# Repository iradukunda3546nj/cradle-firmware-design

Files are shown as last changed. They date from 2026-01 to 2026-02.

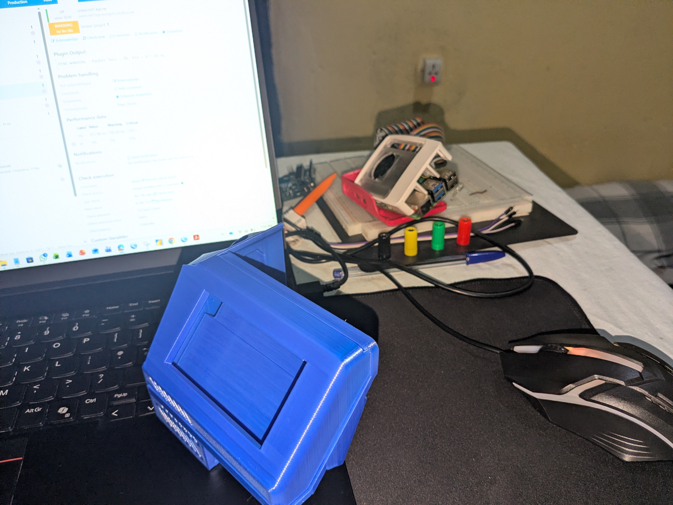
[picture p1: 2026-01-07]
Design Files/des8.jpg

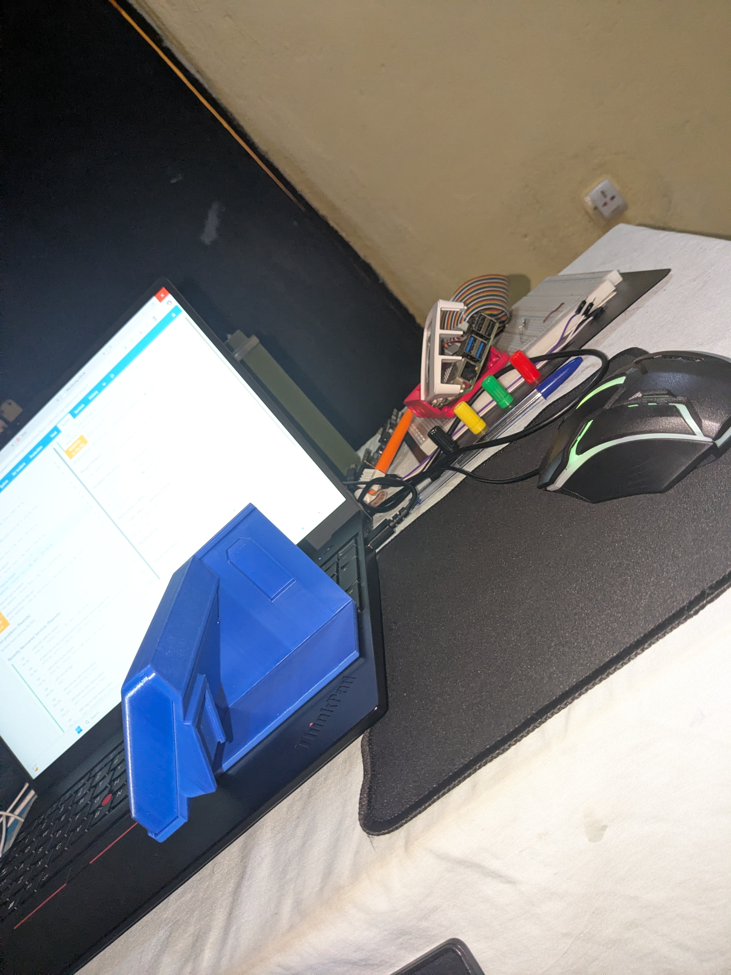
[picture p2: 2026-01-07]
Design Files/des6.jpg

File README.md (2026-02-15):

<<<<<<< HEAD
Git clone

=================

> git clone https://github.com/the-raspberry-pi-guy/lcd

>ls

>cd lcd

>sudo sh install.sh

>Reboot

>Run the demo file as follows:

>python demo_lcd.py  (when you get a Remote I/O error : the problem is on the wrong I2C address of your peripheral connected to the I2C of Raspebrry pi.  

>open lcddriver.py

> nano demo_lcd.py   (check if the I2C address of your lcd matches with the one in the code  : 

 (Here is how to detect the I2C address of your I2C device  : first run

> sudo apt update

> sudo apt install i2c-tools

> Then run : > sudo i2cdetect -y 1    (Note: Please ensure that the I2C is enabled in raspberry pi configurations > raspi-config

If you found that the address of your lcd do not match with the one in the code edit it right and save and exit using the following command

>Ctrl + O → Enter → Ctrl + X

;After running all above I get the realization of this :

Creating VEnv so that you're able to install the libraries using pip:

# Create virtual environment

> python3 -m venv cradlex_env

# Activate the virtual environment

> source cradlex_env/bin/activate

Using Secure copy command

========================================

>scp "D:/cradle-firmware-design/lcdTemp.py" cradle@192.168.1.81:~/       

From Pi to local PC
use e.g > scp cradle@192.168.1.81:~/test.wav "D:/cradle-firmware-design/"                    

                  Re-working on The project

==========================================================================

Recall: to test LCD (we need to go to the lcd folder and run demo_lcd.py)  using the following commands

>cd lcd

>python3 demo_lcd.py

                             Looking for connecting DHT temperature sensor to Rpi

============================================================================================

I have found many works done on connecting DHT sensor to the raspberrypi.However, many of them do not work, when you try to run them you face a runtime error, and this issue might be arising from the lgpio missing library, the one which allows you to interact with the hardware GPIO pins.

Hopefully, Here's a detailed guide to help you connect the digital temperature sensor to the raspberryPi (Go step by step throughout this entire guide).

> https://pimylifeup.com/raspberry-pi-humidity-sensor-dht22/

Now, Let's proceed with installing and connecting RaspberryPi to the edge impulse platform for sending data for model training

===============================================================================

Meanwhile, you can connect the MIC (for me ,I used USB microphone) , CSI camera. (for other sensors you can refer to the way I connected MPU6050 to edge impulse using raspberrypi i.e the way I wrote Python SDK containing API keys of the project).

In fact, connecting raspberrypi to the edge impulse platform requires installing dependencies and the there is an official edge impulse link which streamline process of connecting raspberrypi to the edge impulse 

Follow this:
          >https://docs.edgeimpulse.com/hardware/boards/raspberry-pi-5 

>Then, after you install all dependencies step by step you will run edge_impulse-linux and you will be connected to edge immediately asking you to put the edge impulse account credentials and once you enter them correctly your pi will be connected to edge ,head to that project and then go to devices, then you can start acquiring data from Pi.

                                   Integration of Sensor's data with I2C Lcd Display
===========================================================================================================
The goal was to run all components inside a virtual environment and display real‑time sensor data on the LCD.

During integration, several errors occurred due to legacy libraries, Pi 5 hardware changes, and virtual environment isolation.

This document records each error, its cause, and the exact fix.

Error 1: ModuleNotFoundError: No module named 'smbus'
Error Message

ModuleNotFoundError: No module named 'smbus'

Where it occurred

from smbus import SMBus

Inside:

drivers/i2c_dev.py
Root Cause

The LCD driver uses I2C communication

I2C requires SMBus bindings

smbus is not available inside Python virtual environments by default

Raspberry Pi OS installs smbus at system level, not venv level

Fix Applied (Step‑by‑Step)

Installed system I2C support:

sudo apt update
sudo apt install -y python3-smbus i2c-tools

Installed venv‑compatible SMBus library:

source cradlex_env/bin/activate
pip install smbus2

Updated LCD driver import:

❌ Old:

from smbus import SMBus

✅ New:

from smbus2 import SMBus
Result

✔ SMBus error resolved ✔ I2C communication functional inside virtual environment

Error 2: ModuleNotFoundError: No module named 'RPi'
Error Message
ModuleNotFoundError: No module named 'RPi'
Where it occurred
from RPi.GPIO import RPI_REVISION

Inside:

drivers/i2c_dev.py
Root Cause

Raspberry Pi 5 does not support RPi.GPIO properly

RPi.GPIO is deprecated on Pi 5

Pi 5 officially uses lgpio / libgpiod

The LCD driver was written for older Pi models (3/4)

Virtual environments do not inherit system GPIO libraries

Important Insight

The LCD driver does not actually need GPIO — it only checks RPI_REVISION to guess the I2C bus.

On modern Raspberry Pi models:

I2C bus is always bus 1

Fix Applied (Safe & Engineered)

Modified the driver to gracefully bypass RPi.GPIO:

❌ Old code:

from RPi.GPIO import RPI_REVISION

✅ New code:

try:
    from RPi.GPIO import RPI_REVISION
except ImportError:
    RPI_REVISION = 3  # Safe default for modern Raspberry Pi
Why this works

Avoids installing deprecated RPi.GPIO

Fully compatible with Raspberry Pi 5

Keeps driver future‑proof

Does not interfere with lgpio

Result

✔ GPIO error resolved ✔ LCD driver loads correctly ✔ No conflicts with lgpio

Error 3: Degree Symbol Displaying Incorrectly (-C instead of °C)
Symptom

LCD showed:

25.3-C

Instead of:

25.3°C
Root Cause

HD44780 LCDs do not support Unicode

Unicode degree symbol ° is not part of LCD character ROM

Fix Applied

Used the HD44780‑native degree symbol code:

DEGREE = chr(223)

And updated formatting:

f"{temperature:.1f}{DEGREE}C"
Result

✔ Correct °C symbol displayed

                                         📦 Weighing System Module (Raspberry Pi 5 + HX711 + I2C LCD)
==================================================================================================================================================

1️⃣ Objective

This module adds a reliable digital weighing function to the Raspberry Pi 5 using:

20kg Load Cell

HX711 24-bit ADC amplifier

I2C LCD display

Kalman filtering for stable readings

The goal is to:

Accurately measure weight in kilograms

Provide stable filtered readings

Support calibration using a known weight

Run fully inside a Python virtual environment (cradlex_env)

Be compatible with Raspberry Pi 5 (using lgpio, not RPi.GPIO)

The system is designed for workshop/small-business grade reliability, not hobby-level testing.

2️⃣ Hardware Wiring
HX711 → Raspberry Pi 5 (BCM Numbering)
HX711 Pin	Raspberry Pi 5
DT (DOUT)	GPIO 5
SCK	GPIO 6
VCC	5V
GND	GND

Important Notes:

BCM numbering is used.

Ensure common ground.

Load cell must be mechanically fixed.

Allow 5–10 minutes warm-up before calibration.

3️⃣ Virtual Environment Setup

Activate environment:

source cradlex_env/bin/activate

Install required libraries:

pip install lgpio numpy pyyaml smbus2 RPLCD

System-level dependency:

sudo apt install python3-smbus i2c-tools

4️⃣ Calibration Procedure (calibrate.py)
Purpose

Calibration determines:

zero_offset

calibration_factor

These values convert raw HX711 counts into kilograms.

How It Works

User removes all weight → system measures raw zero value.

User places a known weight → system measures span.

Calibration factor is computed:

calibration_factor = (span_raw - zero_raw) / known_weight

Values are saved into:

config.yaml

How To Run
python3 calibrate.py

Steps:

Remove all weight → press Enter

Enter known weight in kg (e.g., 5)

Place weight → wait stable → press Enter

After completion:

config.yaml

will contain:

zero_offset: XXXXX
calibration_factor: XXXXX

Verification After Calibration

Run:

python3 weighing_system.py

Check:

No load → ~0.000 kg

Known weight → correct value

Remove weight → returns to zero

If slight error exists, fine-tune:

new_factor = old_factor × (measured / real_weight)

5️⃣ Main Weighing Program (weighing_system.py)
Objective

This program:

Reads raw HX711 data

Converts to kg using stored calibration

Applies Kalman filtering

Displays weight on I2C LCD

Runs continuously

Weight Calculation
weight = (raw - zero_offset) / calibration_factor

Filtering

A Kalman filter is applied to:

Reduce noise

Improve stability

Provide smooth readings

Maintain responsiveness

Display

The system shows:

X.XXX kg

Updated continuously.

6️⃣ Important Issue Encountered (SMBus Error)
Problem

While running weighing_system.py, the following error occurred:

NameError: name 'SMBus' is not defined

Root Cause

Inside:

cradlex_env/lib/python3.13/site-packages/RPLCD/i2c.py

The library internally attempted:

self.bus = SMBus(self._port)

However, the module was imported as:

import smbus2 as smbus

This means:

SMBus was not directly defined

Only smbus.SMBus existed

Hence → NameError.

Solution Applied

Opened the file:

nano cradlex_env/lib/python3.13/site-packages/RPLCD/i2c.py

Searched for:

SMBus(

Replaced:

self.bus = SMBus(self._port)

With:

self.bus = smbus.SMBus(self._port)

Saved file.

Result

✔ SMBus error resolved
✔ I2C LCD working inside virtual environment
✔ No need for RPi.GPIO
✔ Compatible with Raspberry Pi 5

7️⃣ Raspberry Pi 5 Compatibility Notes

RPi.GPIO was avoided due to compatibility issues.

lgpio is used instead.

I2C bus on Raspberry Pi 5 is always bus 1.

Virtual environments require smbus2.

8️⃣ Final System Overview

The weighing module now provides:

✔ Pi 5 compatible GPIO control (lgpio)
✔ HX711 24-bit ADC reading
✔ Proper calibration storage
✔ Kalman-filtered stable readings
✔ I2C LCD output
✔ Fully virtual-environment compatible

9️⃣ Future Improvements (Optional)

Add tare button

Add multi-point calibration

Add temperature compensation

Add data logging

Add automatic startup (systemd service)

🔚 Conclusion

The weighing function is now:

Stable

Accurate

Pi 5 compatible

Professionally structured

Fully reproducible from documentation

This documentation ensures future maintenance and upgrades can be performed confidently.

               real embedded-to-server integration || integrating/ sending sensor's data to the cloud platform for Data collection purposes
=================================================================================================================================

=======
>>>>>>> 16ca65192366029ca63078be4c56230614e71125

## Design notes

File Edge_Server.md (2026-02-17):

🌐 Smart Cradle IoT Backend Architecture
📌 System Overview

The Smart Cradle system follows a structured IoT architecture:

Raspberry Pi (Edge Device)
        ↓
HTTP POST Requests (REST API)
        ↓
Server-Side PHP API
        ↓
MySQL Database
        ↓
Dashboard (HTML + CSS + JS)

The project is hosted under:

https://www.zolilabs.com/smart_cradle/

📂 Server Directory Structure

The deployed server folder:

smart_cradle/
│
├── api/
├── audio/
├── dashboard/
├── db/

Each folder has a specific engineering role.

🔹 1️⃣ audio/ – Media Storage Layer
Purpose:

Stores uploaded baby audio recordings.

Logic:

When the Raspberry Pi records audio:

WAV file recorded locally

Converted to MP3

Sent via HTTP POST to:

/smart_cradle/api/upload_audio.php

upload_audio.php saves file to:

smart_cradle/audio/

File is stored with timestamp-based naming:

$fileName = time() . "_" . basename($_FILES["audio"]["name"]);

This prevents filename collisions.

🔹 2️⃣ api/ – REST API Layer

This folder acts as the communication interface between:

Raspberry Pi (device)

Database

Dashboard

It contains:

✅ upload_audio.php
Function:

Receives multipart/form-data POST request.

Logic:

Reads $_FILES["audio"]

Moves file into /audio/

Returns JSON response:

{
  "status": "success",
  "audio_url": "https://www.zolilabs.com/smart_cradle/audio/xxxx.mp3"
}

This URL is later stored in the database.

✅ receive_data.php
Function:

Receives JSON POST request from Raspberry Pi.

Example Payload:
{
  "temperature": 28.3,
  "humidity": 50.2,
  "weight": 5,
  "presence": true,
  "audio_url": "https://..."
}

Logic:

Reads raw JSON body

Decodes into PHP array

Inserts into database table

Returns response

This file is the main IoT ingestion endpoint.

✅ data.php
Function:

Acts as API endpoint for frontend/dashboard.

Purpose:

Provides structured JSON data to the dashboard.

Flow:
Database → data.php → JSON → dashboard JavaScript → UI

This separates:

Data storage logic

Presentation logic

Good engineering separation of concerns.

🔹 3️⃣ db/ – Database Layer

Contains:

Database connection file

Configuration credentials

Possibly schema definitions

Role:

Central persistent storage

Stores:

Temperature

Humidity

Weight

Presence

Audio URL

Timestamp

Acts as historical data source.

🔹 4️⃣ dashboard/ – Visualization Layer
Technology Stack:

HTML

CSS

JavaScript (AJAX / Fetch API)

Logic:

JavaScript periodically requests:

/smart_cradle/api/data.php

Receives JSON response

Dynamically updates:

Temperature display

Humidity display

Weight display

Audio playback

Charts (if implemented)

This creates real-time monitoring interface.

🔁 Complete IoT Data Flow
🔹 Step 1 – Sensor Acquisition (Edge)

Raspberry Pi:

Reads DHT22

Reads HX711 weight

Records audio

Compresses to MP3

🔹 Step 2 – Data Upload

Two separate HTTP requests:

A) Multipart Upload
POST → upload_audio.php
Content-Type: multipart/form-data

B) JSON Upload
POST → receive_data.php
Content-Type: application/json

🔹 Step 3 – Server Processing

PHP validates input

Stores file

Inserts row into MySQL

🔹 Step 4 – Dashboard Retrieval

Frontend makes:

GET → data.php

Receives structured JSON for display.

🧠 Engineering Concepts Applied

This system demonstrates:

RESTful API design

Separation of backend and frontend logic

Edge-to-cloud communication

Multipart/form-data handling

JSON-based IoT communication

Server-side file handling

Database persistence

Web dashboard integration

🔐 Hosting Incident (Bot Protection)

At one point:

LiteSpeed Bot Protection blocked POST requests

IoT device could not solve reCAPTCHA

Server returned HTML instead of JSON

Solution:
Hosting provider whitelisted:

/smart_cradle/api/

This restored automated device communication.

This highlights the importance of:

Understanding server infrastructure

Recognizing HTTP vs application-level failures

Debugging IoT network layers

🏗 Architecture Classification

The Smart Cradle is now a:

Full-stack IoT System

It integrates:

Embedded systems

Real-time sensor acquisition

Digital signal processing

HTTP networking

REST APIs

Database systems

Web dashboards

Hosting infrastructure

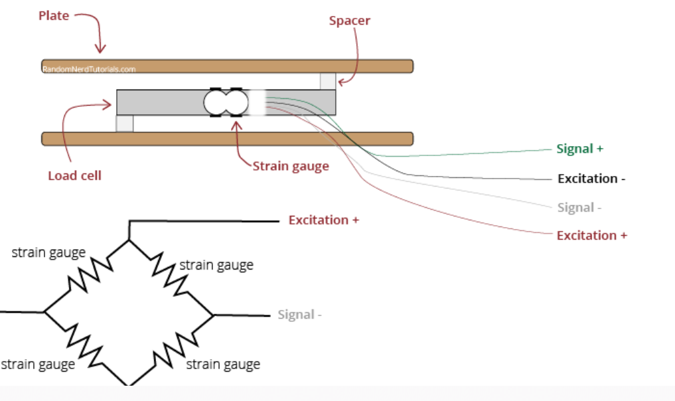
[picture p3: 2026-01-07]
LoadcellOverview.png

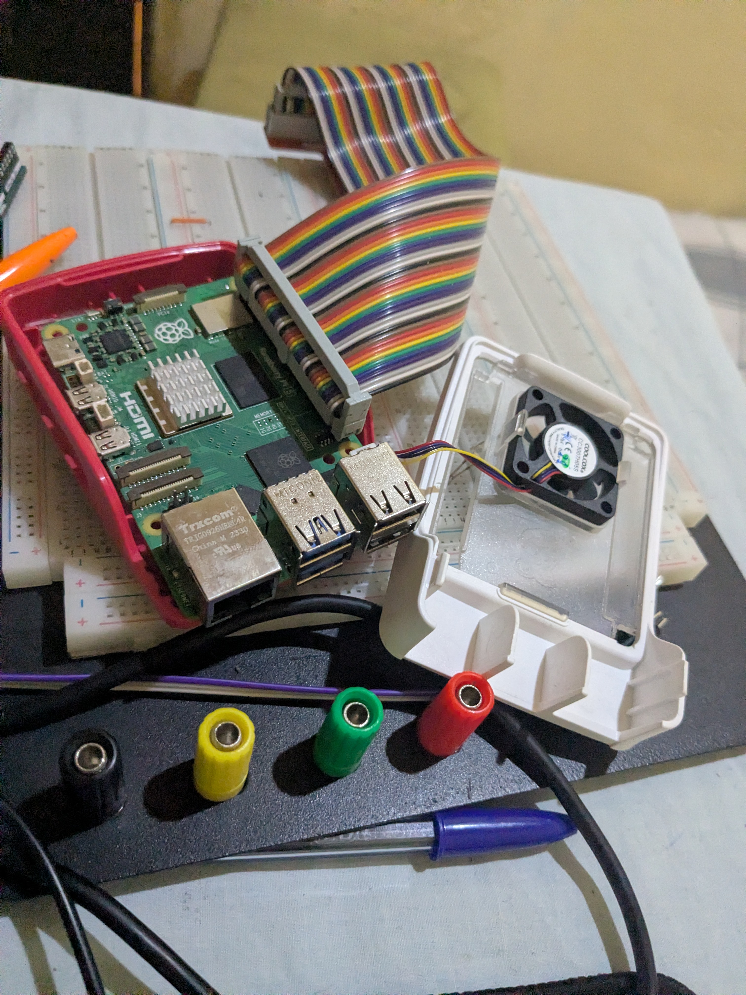
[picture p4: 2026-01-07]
Design Files/des5.jpg

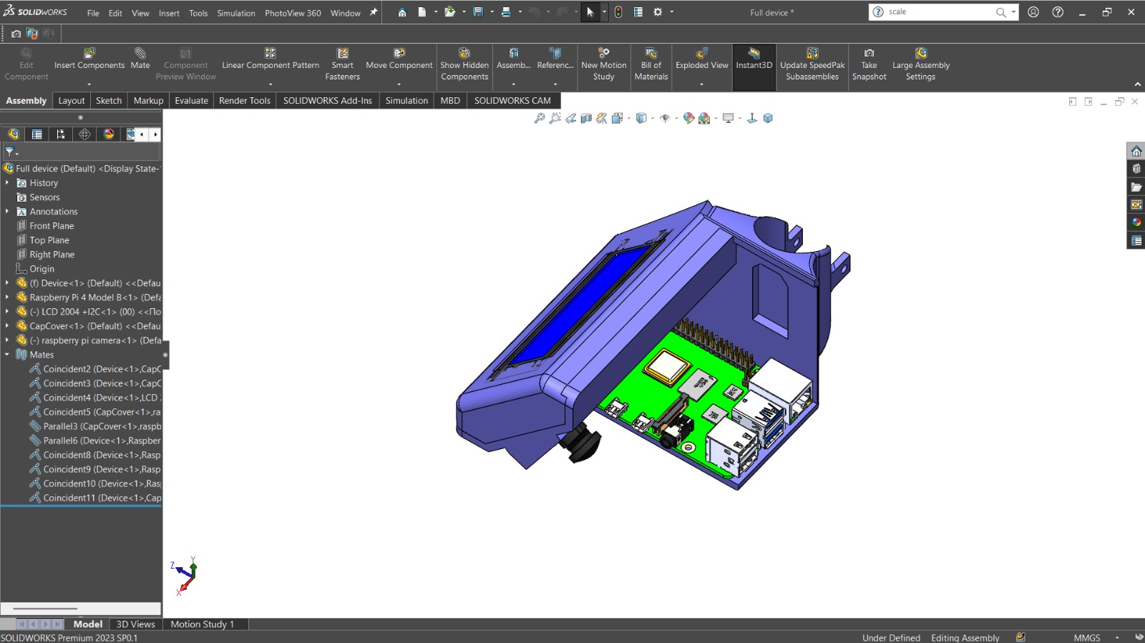
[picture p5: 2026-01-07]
Design Files/des4.jpeg

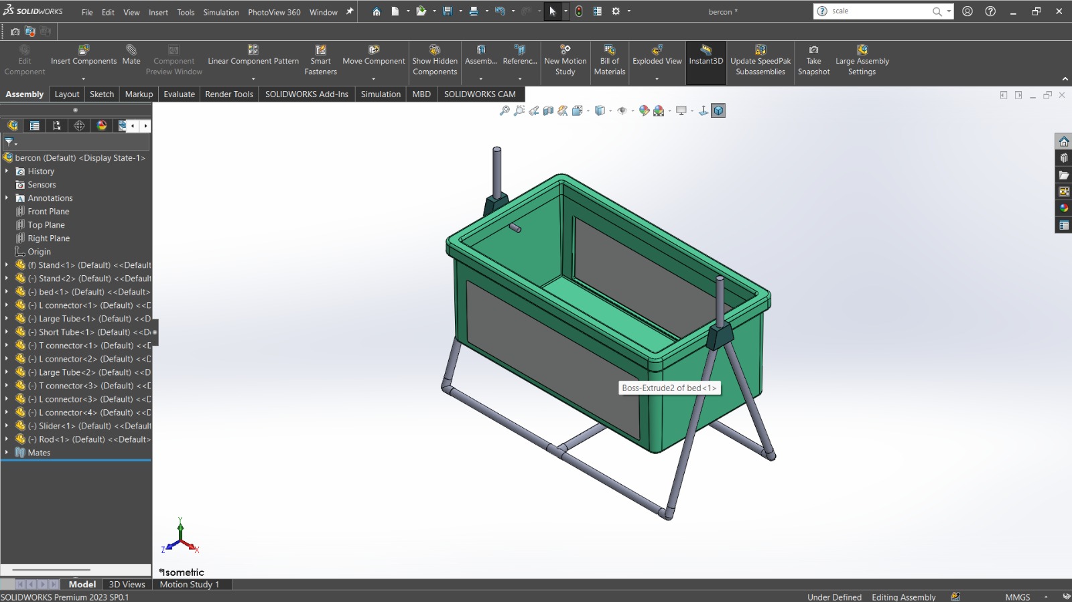
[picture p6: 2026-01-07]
Design Files/des3.jpeg

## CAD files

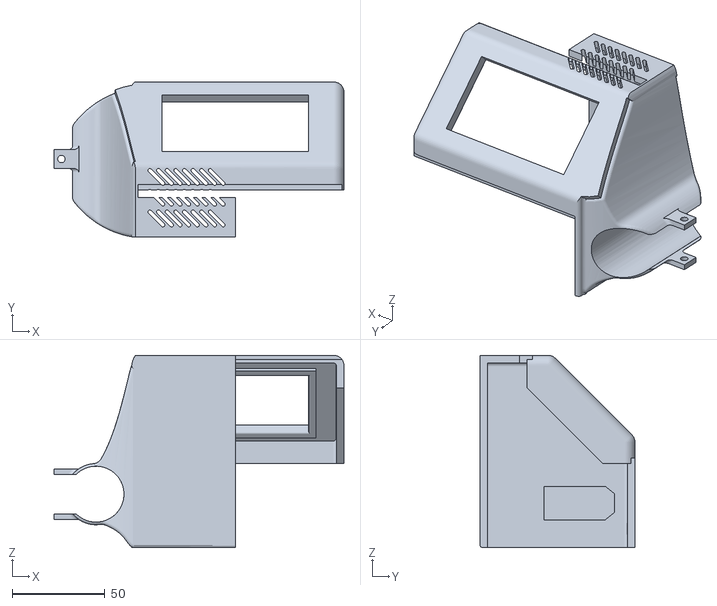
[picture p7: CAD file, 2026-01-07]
Design Files/Device.STL
156.1 x 83.5 x 103.5

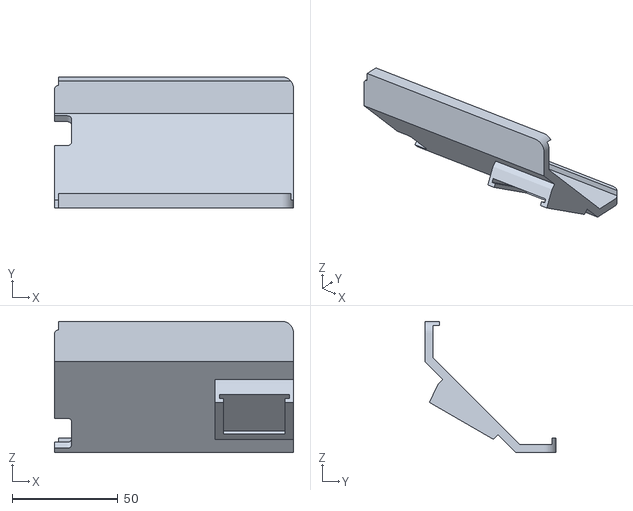
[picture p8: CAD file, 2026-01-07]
Design Files/CapCover.STL
113.0 x 62.1 x 62.1

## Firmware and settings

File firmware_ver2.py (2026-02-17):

import time
import threading
import statistics
from urllib.parse import urlparse
import board
import adafruit_dht
import drivers
import subprocess
import requests
import json
import os
import lgpio
import yaml

# ------------------ CONFIG ------------------

PC_IP = "https://www.zolilabs.com"

def normalize_base_url(base: str) -> str:
    parsed = urlparse(base)
    if parsed.scheme and parsed.netloc:
        return f"{parsed.scheme}://{parsed.netloc}"
    return f"https://{base.strip().rstrip('/')}"

BASE_URL = normalize_base_url(PC_IP)
AUDIO_UPLOAD_URL = f"{BASE_URL}/smart_cradle/api/upload_audio.php"
DATA_UPLOAD_URL = f"{BASE_URL}/smart_cradle/api/receive_data.php"

AUDIO_WAV = "/tmp/cry.wav"
AUDIO_MP3 = "/tmp/cry.mp3"
RECORD_SECONDS = 5

# ------------------ INITIALIZATION ------------------

dht_device = adafruit_dht.DHT22(board.D4)
display = drivers.Lcd()
DEGREE = chr(223)

# ------------------ WEIGHT SYSTEM ------------------

DT = 5
SCK = 6
CONFIG_FILE = "config.yaml"

with open(CONFIG_FILE) as f:
    cfg = yaml.safe_load(f)

zero_offset = cfg["zero_offset"]
cal_factor = cfg["calibration_factor"]

chip = lgpio.gpiochip_open(0)
lgpio.gpio_claim_input(chip, DT)
lgpio.gpio_claim_output(chip, SCK)

# Industrial parameters
SAMPLE_COUNT = 20
AUTO_ZERO_THRESHOLD = 0.3   # kg
PRESENCE_THRESHOLD = 2.0    # kg (baby detection)
TEMP_COEFF = -0.002         # kg per °C (simple compensation)

current_weight = 0.0
weight_lock = threading.Lock()

def read_raw():
    while lgpio.gpio_read(chip, DT) == 1:
        time.sleep(0.0005)

    count = 0
    for _ in range(24):
        lgpio.gpio_write(chip, SCK, 1)
        count <<= 1
        lgpio.gpio_write(chip, SCK, 0)
        if lgpio.gpio_read(chip, DT):
            count += 1

    lgpio.gpio_write(chip, SCK, 1)
    lgpio.gpio_write(chip, SCK, 0)

    if count & 0x800000:
        count -= 0x1000000

    return count

def weight_acquisition_thread():
    global current_weight, zero_offset

    while True:
        samples = []
        for _ in range(SAMPLE_COUNT):
            raw = read_raw()
            weight = (raw - zero_offset) / cal_factor
            samples.append(weight)
            time.sleep(0.01)

        median_val = statistics.median(samples)
        filtered = [s for s in samples if abs(s - median_val) < 0.5]

        if not filtered:
            continue

        avg_weight = sum(filtered) / len(filtered)

        # Auto-zero correction (slow drift removal)
        if abs(avg_weight) < AUTO_ZERO_THRESHOLD:
            zero_offset += (avg_weight * cal_factor * 0.001)

        # Temperature compensation
        try:
            temp = dht_device.temperature
            if temp is not None:
                avg_weight += TEMP_COEFF * (temp - 25)
        except:
            pass

        # Commercial rounding
        rounded = round(avg_weight)

        with weight_lock:
            current_weight = max(0, rounded)

        time.sleep(0.2)

# Start weight thread
threading.Thread(target=weight_acquisition_thread, daemon=True).start()

def get_weight():
    with weight_lock:
        return current_weight

# ------------------ LCD ------------------

def lcd_write(text, line):
    display.lcd_display_string(text.ljust(16)[:16], line)

# ------------------ AUDIO ------------------

def record_audio():
    device_options = ["plughw:2,0", "hw:2,0", "default"]

    for device in device_options:
        try:
            cmd = [
                "arecord",
                "-D", device,
                "-d", str(RECORD_SECONDS),
                "-f", "cd",
                AUDIO_WAV
            ]

            result = subprocess.run(cmd, timeout=RECORD_SECONDS + 5)

            if result.returncode == 0:
                return os.path.exists(AUDIO_WAV)

        except:
            pass

    return False

def convert_to_mp3():
    if not os.path.exists(AUDIO_WAV):
        return False

    result = subprocess.run(
        ["lame", "--silent", AUDIO_WAV, AUDIO_MP3]
    )

    return result.returncode == 0 and os.path.exists(AUDIO_MP3)

def upload_audio():
    if not os.path.exists(AUDIO_MP3):
        return None

    try:
        with open(AUDIO_MP3, "rb") as f:
            files = {"audio": ("cry.mp3", f, "audio/mpeg")}
            r = requests.post(AUDIO_UPLOAD_URL, files=files, timeout=20)

        try:
            return r.json().get("audio_url")
        except:
            return None
    except:
        return None

# ------------------ SEND DATA ------------------

def send_data(temp, hum, weight, audio_url):
    payload = {
        "temperature": temp,
        "humidity": hum,
        "weight": weight,
        "presence": weight >= PRESENCE_THRESHOLD,
        "audio_url": audio_url if audio_url else ""
    }

    try:
        requests.post(
            DATA_UPLOAD_URL,
            data=json.dumps(payload),
            headers={"Content-Type": "application/json"},
            timeout=5
        )
    except:
        pass

# ------------------ MAIN LOOP ------------------

def main():
    display.lcd_clear()
    lcd_write("Smart BabyCradle", 1)
    lcd_write("System Starting", 2)
    time.sleep(2)

    while True:
        try:
            temp = dht_device.temperature
            hum = dht_device.humidity
            weight = get_weight()

            display.lcd_clear()
            lcd_write("Smart BabyCradle", 1)

            if temp and hum:
                lcd_write(f"Temp:{temp:.1f}{DEGREE}C", 2)
                lcd_write(f"Hum :{hum:.0f}%", 3)
            else:
                lcd_write("Sensor Error", 2)

            lcd_write(f"Weight:{weight} Kg", 4)

            print(f"T:{temp} H:{hum} W:{weight}")

            # Send every 5 seconds
            send_data(temp, hum, weight, None)

            time.sleep(5)

        except Exception as e:
            print("Main loop error:", e)
            time.sleep(3)

if __name__ == "__main__":
    try:
        main()
    except KeyboardInterrupt:
        lgpio.gpiochip_close(chip)
        display.lcd_clear()

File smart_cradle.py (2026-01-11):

import time
from urllib.parse import urlparse
import random
import board
import adafruit_dht
import drivers
import subprocess
import requests
import json
import os

# ------------------ CONFIG ------------------

PC_IP = "https://www.zolilabs.com"  # Can be domain or full URL

def normalize_base_url(base: str) -> str:
    parsed = urlparse(base)
    if parsed.scheme and parsed.netloc:
        base_url = f"{parsed.scheme}://{parsed.netloc}"
    else:
        base = base.strip().rstrip('/')
        base_url = f"https://{base}"  # default to HTTPS
    return base_url.rstrip('/')

BASE_URL = normalize_base_url(PC_IP)
print(f"Using server base URL: {BASE_URL}")
AUDIO_UPLOAD_URL = f"{BASE_URL}/smart_cradle/api/upload_audio.php"
DATA_UPLOAD_URL = f"{BASE_URL}/smart_cradle/api/receive_data.php"

AUDIO_WAV = "/tmp/cry.wav"
AUDIO_MP3 = "/tmp/cry.mp3"
RECORD_SECONDS = 5  # Reduced for testing, change back to 30 when working

# ------------------ INITIALIZATION ------------------

dht_device = adafruit_dht.DHT22(board.D4)
display = drivers.Lcd()
DEGREE = chr(223)

# ------------------ FUNCTIONS ------------------

def get_weight():
    """Simulated baby weight (kg)"""
    return round(random.uniform(5, 20), 1)

def lcd_write(text, line):
    display.lcd_display_string(text.ljust(16)[:16], line)

def record_audio():
    """Record audio from USB microphone"""
    try:
        lcd_write("Recording...", 4)
        
        # Test if audio device exists first
        test_cmd = ["arecord", "-l"]
        result = subprocess.run(test_cmd, capture_output=True, text=True)
        print("Audio devices detected:")
        print(result.stdout)
        
        # Alternative device specifications to try
        device_options = [
            "plughw:2,0",    # Direct hardware access
            "hw:2,0",        # Alternative hardware syntax
            "default",       # System default
        ]
        
        success = False
        for device in device_options:
            try:
                print(f"Trying device: {device}")
                cmd = [
                    "arecord",
                    "-D", device,
                    "-d", str(RECORD_SECONDS),
                    "-f", "cd",
                    "-v",  # Verbose output for debugging
                    AUDIO_WAV
                ]
                
                print(f"Running command: {' '.join(cmd)}")
                result = subprocess.run(
                    cmd, 
                    stdout=subprocess.PIPE, 
                    stderr=subprocess.PIPE,
                    text=True,
                    timeout=RECORD_SECONDS + 5
                )
                
                if result.returncode == 0:
                    print(f"Recording successful with device: {device}")
                    success = True
                    break
                else:
                    print(f"Failed with device {device}: {result.stderr}")
                    
            except subprocess.TimeoutExpired:
                print(f"Recording timeout with device: {device}")
            except Exception as e:
                print(f"Error with device {device}: {str(e)}")
        
        if success:
            # Verify file was created
            if os.path.exists(AUDIO_WAV):
                file_size = os.path.getsize(AUDIO_WAV)
                print(f"Audio file created: {AUDIO_WAV}, Size: {file_size} bytes")
                return True
            else:
                print("Audio file was not created")
                return False
        else:
            print("All device options failed")
            return False
            
    except Exception as e:
        print(f"Error in record_audio: {str(e)}")
        return False

def convert_to_mp3():
    """Convert WAV to MP3"""
    try:
        if not os.path.exists(AUDIO_WAV):
            print(f"WAV file not found: {AUDIO_WAV}")
            return False
        
        print("Converting to MP3...")
        result = subprocess.run(
            ["lame", "--silent", AUDIO_WAV, AUDIO_MP3],
            capture_output=True,
            text=True
        )
        
        if result.returncode == 0 and os.path.exists(AUDIO_MP3):
            print(f"Converted to MP3: {AUDIO_MP3}")
            return True
        else:
            print(f"Conversion failed: {result.stderr}")
            return False
            
    except Exception as e:
        print(f"Error in convert_to_mp3: {str(e)}")
        return False

def upload_audio():
    """Upload audio file to server"""
    try:
        if not os.path.exists(AUDIO_MP3):
            print(f"MP3 file not found: {AUDIO_MP3}")
            return None
            
        lcd_write("Uploading audio", 4)
        print(f"Uploading {AUDIO_MP3}...")
        
        with open(AUDIO_MP3, "rb") as f:
            r = requests.post(AUDIO_UPLOAD_URL, files={"audio": f}, timeout=30)
        
        print(f"Upload response: {r.status_code}")
        if r.status_code == 200:
            response = r.json()
            print(f"Upload successful: {response}")
            return response.get("audio_url")
        else:
            print(f"Upload failed: {r.text}")
            return None
            
    except Exception as e:
        print(f"Error in upload_audio: {str(e)}")
        return None

def send_data(temp, hum, weight, audio_url):
    """Send sensor data to server"""
    try:
        lcd_write("Sending data", 4)
        print("Sending sensor data...")
        
        payload = {
            "temperature": temp,
            "humidity": hum,
            "weight": weight,
            "audio_url": audio_url if audio_url else ""
        }
        
        headers = {"Content-Type": "application/json"}
        response = requests.post(
            DATA_UPLOAD_URL, 
            data=json.dumps(payload), 
            headers=headers, 
            timeout=10
        )
        
        print(f"Data sent: Status {response.status_code}")
        
    except Exception as e:
        print(f"Error in send_data: {str(e)}")

# ------------------ MAIN LOOP ------------------
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

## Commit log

2026-02-15 Weight calibration program
2026-02-15 weighing system program and we insert the calibration factor i.e the one calculated from cabrate.py
2026-02-17 This file named firmware_Ver1.py is an updated version of smart_cradle.py which replaces the random function for reading weight by the real weight sensor/load cell reading.
    [firmware_Ver1.py]
2026-02-17 This is an updated version of firmware_ver1.py , improvements are: stabilized weight sensing logic, architechure changed to multithread instead of being a single loop to avoid the networl delays bloc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
    [firmware_ver2.py]
2026-02-17 This is a extended readMe file which explains how edge device (Raspberrypi) connects to the Server and then the data flow from server to the dashboard and production ready API end points.
